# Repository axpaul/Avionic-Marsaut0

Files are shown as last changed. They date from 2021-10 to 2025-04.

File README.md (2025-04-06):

# Avionic Marsaut 0

> *© 2021 Paul Miailhe, all rights reserved.*  
> *Material licensed under [→ CC BY-NC-SA 4.0](https://creativecommons.org/licenses/by-nc-sa/4.0)*

## Experimental Rocket Avionics for Marsaut 0

The **Marsaut 0 avionics system**, designed and developed by Paul Miailhe in 2021, was successfully launched during the C'Space event. This project is licensed under **CC BY-NC-SA 4.0**.

The avionics system is based on an **STM32F303K8** microcontroller, which provides high-performance real-time control for the rocket's systems. It integrates essential sensors, motor drivers, and interface boards to ensure a robust and reliable solution for experimental rocketry.

You can access the CAD designs for all the boards [here on GrabCAD](https://grabcad.com/library/avionics-system-for-marsaut-0-rocket-mines-space-1).

---

## System Overview

The electronic architecture of the rocket is divided into the following branches:

---

- **Branch APU** (Acquisition Process Unit):  
  Responsible for acquiring, storing, and transmitting data, equipped with:  
  - **MPU6050**: A 6-axis gyroscope and accelerometer for attitude measurement.  
  - **BMP280**: A barometric pressure sensor for altitude estimation.

<p align="center">
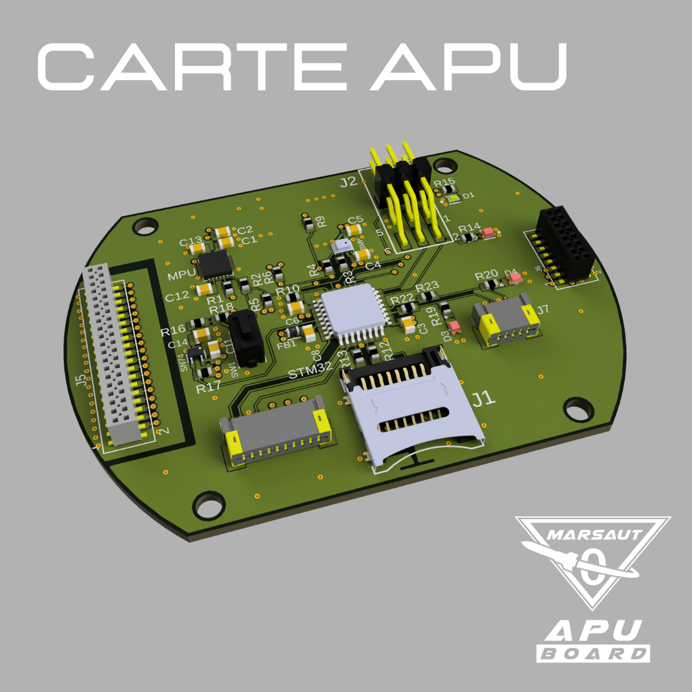
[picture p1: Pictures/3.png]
Carte APU
  
</p>

---

- **Branch SEQ** (Flight Controller):  
  The core control board, based on the **STM32F303K8**, which manages actuators and flight status monitoring.

  <p align="center">
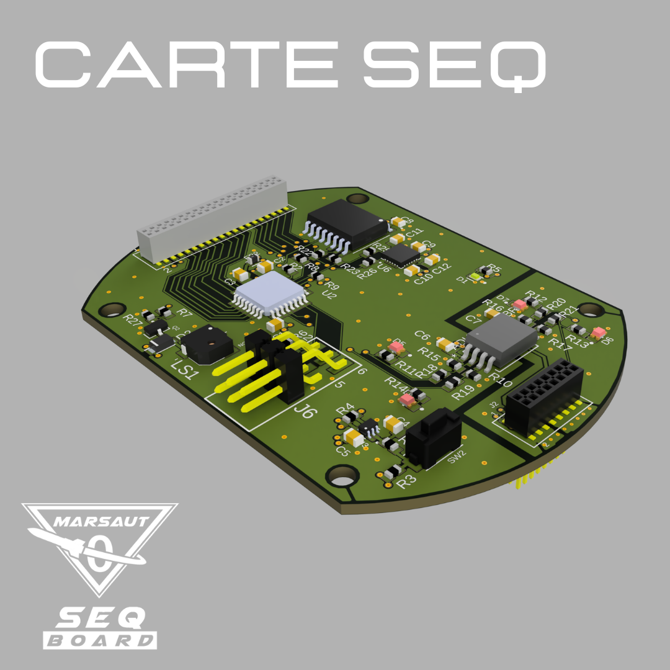
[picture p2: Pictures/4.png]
Carte SEQ
  
</p>

---

- **Branch ALIM** (Power Supply):  
  Handles power distribution and monitors the battery's state of charge.
  
  <p align="center">
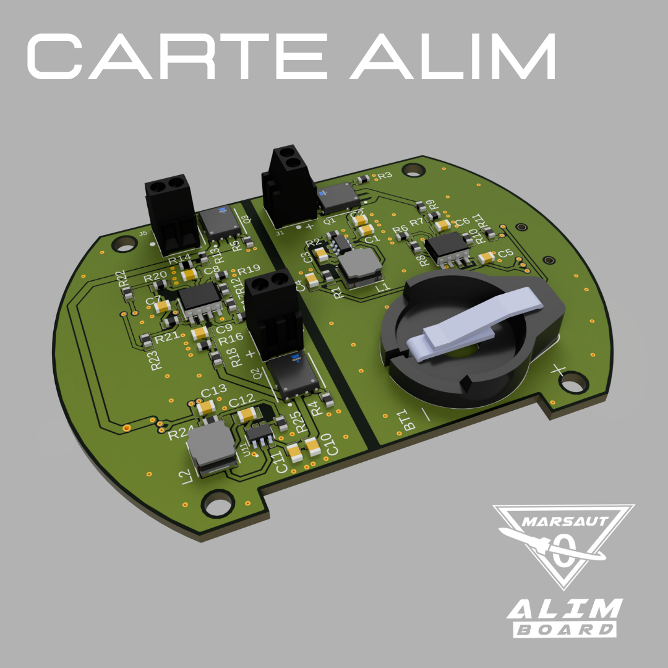
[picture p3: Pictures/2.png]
Carte ALIM
  
</p>

---

- **Branch MOTOR**:  
  Includes two **VNH5019 motor drivers** (by STMicroelectronics) for controlling the parachute deployment system.

  <p align="center">
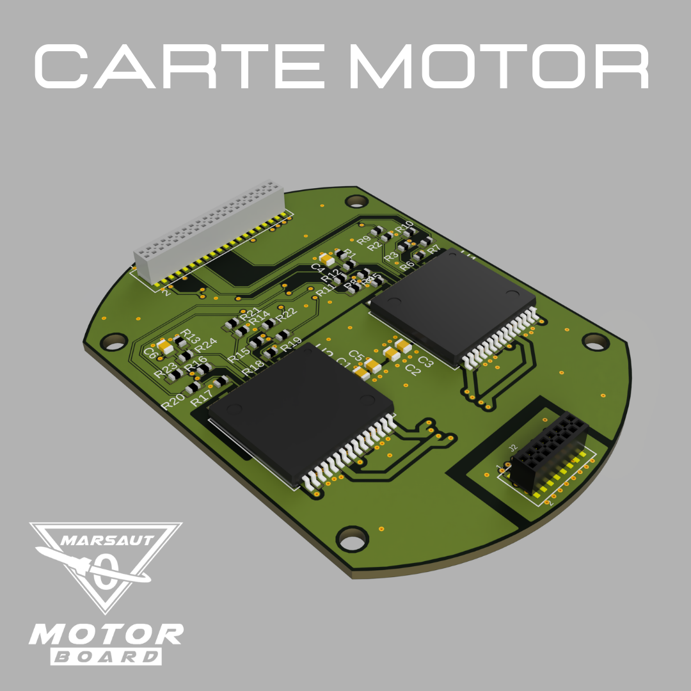
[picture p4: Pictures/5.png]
Carte MOTOR
  
</p>

---

- **Branch LINK**:  
  Connects all actuators and sensors in the rocket to the avionics for seamless operation.

    <p align="center">
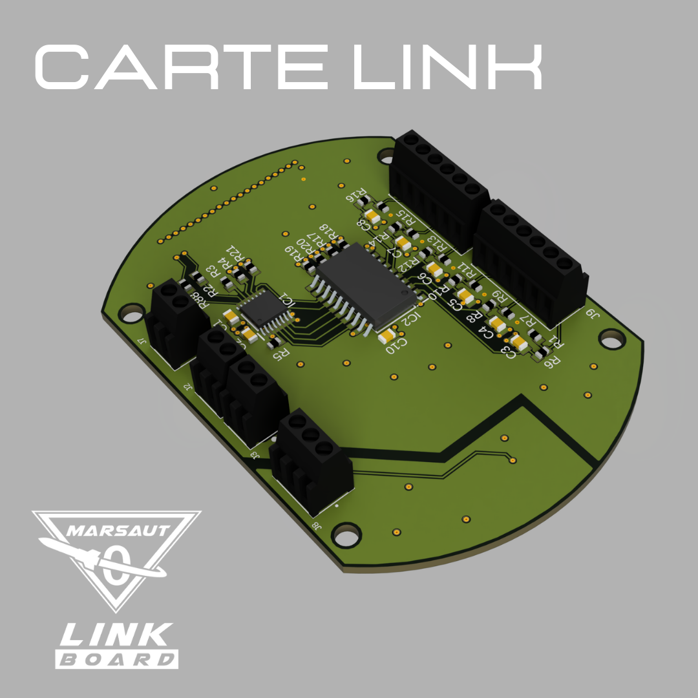
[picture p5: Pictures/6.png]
Carte LINK
  
</p>

---

- **Branch HMI** (Human-Machine Interface):  
  Provides a user interface for controlling the system and displaying key information.

---

- **Branch INT_LTS**:  
  Serves as the interface for integrating the **LoRa TTGO-T BEAM** communication module.

---

## Key Components

### **Microcontroller**
- **STM32F303K8**:  
  - ARM Cortex-M3 core with floating-point unit (FPU).  
  - Provides real-time control and data processing capabilities.

### **Sensors**
- **MPU6050**:  
  - A 6-axis IMU for measuring acceleration and angular velocity.  
  - Enables precise attitude and motion tracking.
- **BMP280**:  
  - A barometric pressure sensor for accurate altitude estimation.

### **Motor Drivers**
- **VNH5019** (by STMicroelectronics):  
  - High-power motor drivers capable of handling currents up to 12A.  
  - Used to control the parachute deployment mechanism with precision.

---

## Features and Applications

- **Real-time Control**:  
  The STM32F303K8 ensures smooth operation of actuators and sensors.  

- **Integrated Sensors**:  
  MPU6050 and BMP280 provide reliable data for navigation and altitude tracking.

- **High-Performance Motor Control**:  
  The VNH5019 motor drivers ensure precise parachute deployment and safety.

- **Seamless Communication**:  
  LoRa TTGO-T BEAM module enables efficient data transmission to ground stations.

---

## Visual Overview

### Avionics System CAD
You can find the full CAD designs of the avionics system on [GrabCAD](https://grabcad.com/library/avionics-system-for-marsaut-0-rocket-mines-space-1).

### Images
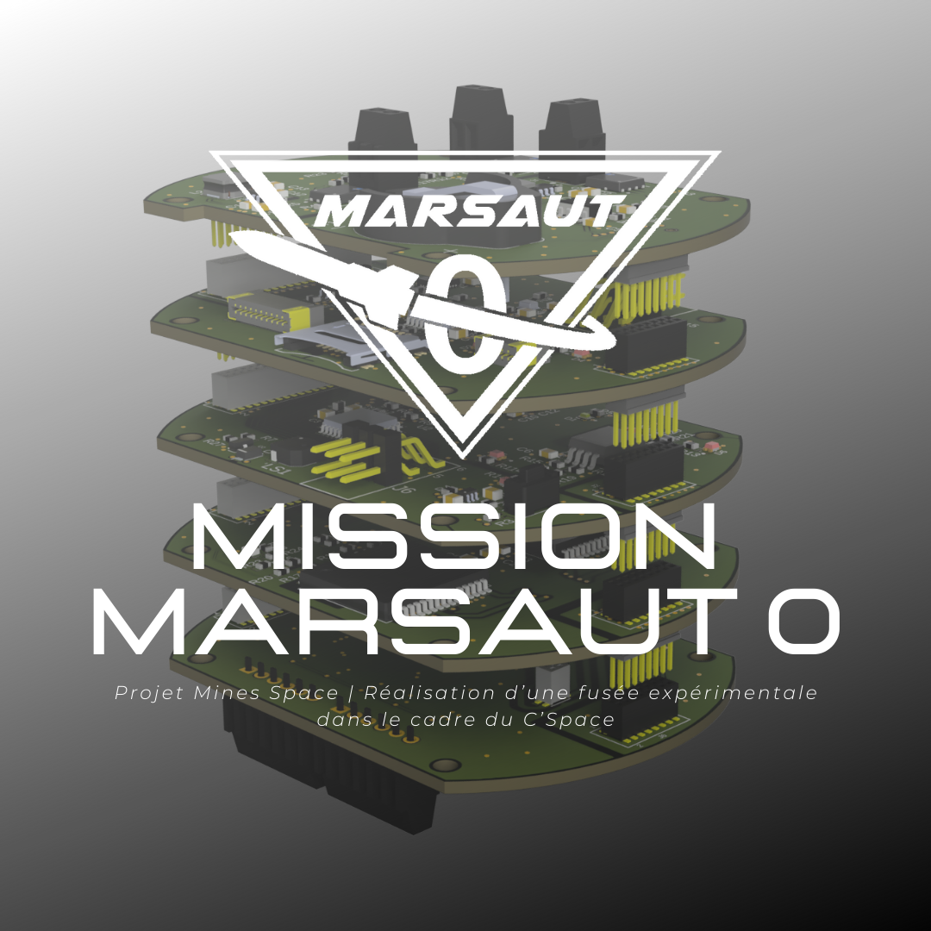
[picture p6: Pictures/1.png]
Marsaut 0 Avionics


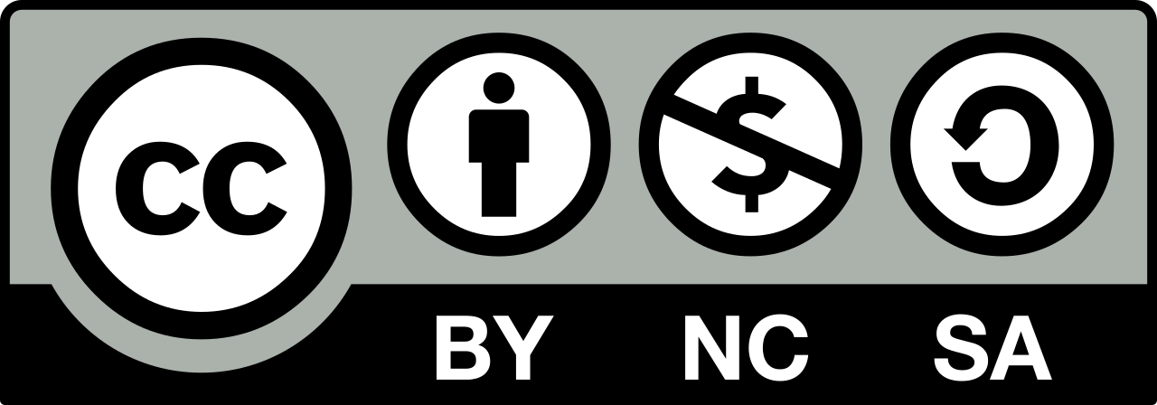
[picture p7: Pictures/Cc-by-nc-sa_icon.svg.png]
Creative Commons License


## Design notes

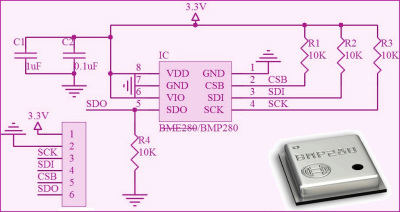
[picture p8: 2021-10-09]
LIB_MS0/Capteur/BMP280/Datasheet/3-BMP280-Module_Schematic.jpg

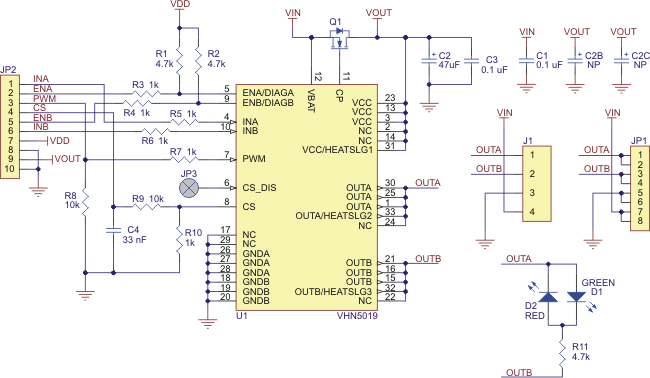
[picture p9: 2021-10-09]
LIB_MS0/DriverMotor/VNH5019ATR-E/shematic/0J3696.650.png

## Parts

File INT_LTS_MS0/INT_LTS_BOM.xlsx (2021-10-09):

Qty | Value | Device | Package | Parts | Description
2 |  | PINHD-1X13 | 1X13 | JP1, JP2 | PIN HEADER
2 | 0R | R-EU_R0603 | R0603 | R1, R2 | RESISTOR, European symbol
2 | 110R | R-EU_R0603 | R0603 | R3, R15 | RESISTOR, European symbol
1 | BROADCOM_HSMA-C190BROADCOM_HSMA-C190_0_0 | BROADCOM_HSMA-C190BROADCOM_HSMA-C190_0_0 | BROADCOM_HSMA-C190_0 | LED_APU_AMBER | Amber 592nm LED Indication - Discrete 1.9V 0603 (1608 Metric)
1 | BROADCOM_HSMH-C170BROADCOM_HSMH-C170_0_0 | BROADCOM_HSMH-C170BROADCOM_HSMH-C170_0_0 | BROADCOM_HSMH-C170_0 | LED_APU_RED | LED RED DIFFUSED 0805 SMD
1 | FC1-05-02-T-WT-TR | FC1-05-02-T-WT-TR | FC10502TWTTR | J7 | FFC & FPC Connectors 1.00 mm Flat Flexible Cable (FFC) Socket Strip

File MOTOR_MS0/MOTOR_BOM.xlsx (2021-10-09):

Qty | Value | MPN | Package | Parts | Description | LCSC Part
10 | 0R | 0603WAF0000T5E | R0603 | R7, R8, R9, R10, R11, R19, R20, R21, R22, R23 | RESISTOR, European symbol | C21189
6 | 100K | 0603WAF1003T5E | R0603 | R2, R5, R6, R14, R17, R18 | RESISTOR, European symbol | C25803
2 | 10k | 0603WAF1002T5E | R0603 | R12, R24 | RESISTOR, European symbol | C25804
2 | 33nF | 0805B333K500NT | C0805 | C4, C6 | CAPACITOR, European symbol | C1739
4 | 3K3 | 0603WAF3301T5E | R0603 | R3, R4, R15, R16 | RESISTOR, European symbol | C22978
4 | 22uF | CL21A226MAQNNNE | C0805 | C1, C2, C3, C5 | CAPACITOR, European symbol | C45783
2 | 5K6 | 0603WAF5601T5E | R0603 | R1, R13 | RESISTOR, European symbol | C23189
1 | FLE-108-01-XX-DV | NON-CONNECTED | FLE-108-01-XX-DV | J2 | DOUBLE ROW 0.050X0.050" STRIP ASSEMBLY. Check prices"
1 | FLE-120-01-XX-DV | NON-CONNECTED | FLE-120-01-XX-DV | J5 | DOUBLE ROW 0.050X0.050" STRIP ASSEMBLY. Check prices"
1 | FTSH-102-05-F-DV | NON-CONNECTED | FTSH-102-XX-YYY-DV | J1 | 4 Position, High Reliability Header Strips, 0.050 pitch"
1 | FTSH-108-05-F-DV-A | NON-CONNECTED | FTSH-108-XX-YYY-DV-A | J4 | 16 Position, High Reliability Header Strips, 0.050 pitch"
1 | FTSH-120-05-F-DV | NON-CONNECTED | FTSH-120-XX-YYY-DV | J3 | 40 Position, High Reliability Header Strips, 0.050 pitch"
2 | VNH5019ATR-E | NON-CONNECTED | IC_VNH5019ATR-E | U1, U2 | Motor / Motion / Ignition Controllers & Drivers Automotive h-Bridge 18mohm 30a 41v Vcc Check prices

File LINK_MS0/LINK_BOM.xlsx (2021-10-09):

Qty | Value | MPN | Package | Parts | Description | LCSC Part
8 | 0R | 0603WAF0000T5E | R0603 | R2, R4, R17, R18, R19, R20, R21, R88 | RESISTOR, European symbol | C21189
9 | 100nF | CC0805KRX7R9BB104 | C0805 | C1, C2, C3, C4, C5, C6, C7, C8, C10 | CAPACITOR, European symbol | C49678
13 | 10K | 0603WAF1002T5E | R0603 | R1, R3, R6, R7, R8, R9, R10, R11, R12, R13, R14, R15, R16 | RESISTOR, European symbol | C25804
3 | 282834-2 | NON-CONNECTED | CONN_282834-2 | J2, J3, J7 | Terminal block; 2.54mm; angled 90Â°; 0.03Ã·1mm2; ways: 2; 10A; H: 10mm Check prices
1 | 282834-3 | NON-CONNECTED | TE_282834-3 | J8 | Conn; Term Blk; PCB; Wire Receptacle; 3; 2.54mm; 30-16AWG; Green; 10A; 150V; M1.6 Check prices
2 | 282834-6 | NON-CONNECTED | TE_282834-6 | J4, J9 | TERM BLOCK 6POS SIDE ENT 2.54MM Check prices
1 | 4K7 | 0603WAF4701T5E | R0603 | R5 | RESISTOR, European symbol | C23162
1 | 74HC7541D,118 | NON-CONNECTED | SOIC127P1032X265-20N | IC2 | 74HC(T)7541 - Octal Schmitt trigger buffer/line driver; 3-state@en-us
1 | FLE-102-01-G-DV | NON-CONNECTED | SAMTEC_FLE-102-01-G-DV | J1 | Check prices
1 | FLE-108-01-XX-DV | NON-CONNECTED | FLE-108-01-XX-DV | J6 | DOUBLE ROW 0.050X0.050" STRIP ASSEMBLY. Check prices"
1 | FLE-120-01-XX-DV | NON-CONNECTED | FLE-120-01-XX-DV | J5 | DOUBLE ROW 0.050X0.050" STRIP ASSEMBLY. Check prices"
1 | TCA6408AQPWRQ1 | NON-CONNECTED | SOP65P640X120-16N | IC1 | Automotive Low-Voltage 8-Bit I2C and SMBus I/O Expander With Interrupt Output

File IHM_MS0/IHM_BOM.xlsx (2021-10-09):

Qty | Value | MPN | Package | Parts | Description | LCSC Part
1 |  | NON-CONNECTED | 1X04 | JP1 | PIN HEADER
3 | 0R | 0603WAF0000T5E | R0603 | R2, R4, R21 | RESISTOR, European symbol | C21189
5 | 100nF | CC0805KRX7R9BB104 | C0805K | C1, C2, C4, C6, C8 | CAPACITOR, European symbol | C49678
4 | 10K | 0603WAF1002T5E | R0603 | R3, R6, R7, R20 | RESISTOR, European symbol | C25804
7 | 110R | NON-CONNECTED | R0603 | R1, R13, R14, R15, R16, R17, R18 | RESISTOR, European symbol
3 | 147873-1 | NON-CONNECTED | SW_147873-1 | SW1, SW2, SW3 | Switch Tactile OFF (ON) SPST Rectangular Button J-Bend 0.05A 24VDC 1.77N SMD T/R Check prices
3 | 1K | 0603WAF1001T5E | R0603 | R10, R11, R12 | RESISTOR, European symbol | C21190
3 | 2u2F | 0805F225M500NT | C0805K | C3, C5, C7 | CAPACITOR, European symbol | C49217
1 | 4K7 | 0603WAF4701T5E | R0603 | R5 | RESISTOR, European symbol | C23162
3 | BROADCOM_ASMT-RF45-AN002BROADCOM_ASMT-RF45-AN002_0_0 | NON-CONNECTED | BROADCOM_ASMT-RF45-AN002_0 | LAG, LMG, LSG | LED YLW/GREEN DIFFUSED 0603 SMD
1 | BROADCOM_HSMA-C190BROADCOM_HSMA-C190_0_0 | NON-CONNECTED | BROADCOM_HSMA-C190_0 | LIP | Amber 592nm LED Indication - Discrete 1.9V 0603 (1608 Metric)
3 | BROADCOM_HSMH-C170BROADCOM_HSMH-C170_0_0 | NON-CONNECTED | BROADCOM_HSMH-C170_0 | LAR, LMR, LSD | LED RED DIFFUSED 0805 SMD
1 | FC1-10-02-T-WT-TR | NON-CONNECTED | FC11002TWTTR | J1 | FFC & FPC Connectors 1.00 mm Flat Flexible Cable (FFC) Socket Strip
3 | SN74LVC1G17DCKR | NON-CONNECTED | SOT65P210X110-5N | U1, U2, U3 | Check prices
1 | TCA6408AQPWRQ1 | NON-CONNECTED | SOP65P640X120-16N | IC1 | Automotive Low-Voltage 8-Bit I2C and SMBus I/O Expander With Interrupt Output

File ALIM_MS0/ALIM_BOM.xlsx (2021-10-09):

Qty | Value | MPN | Package | Parts | Description | LCSC Part Number(optional)
3 | 0R | 0603WAF0000T5E | R0603 | R11, R22, R23 | RESISTOR, European symbol | C21189
3 | 100R | NON-CONNECTED | R0603 | R3, R4, R5 | RESISTOR, European symbol
6 | 100nF | CC0805KRX7R9BB104 | C0805 | C1, C3, C5, C7, C10, C12 | CAPACITOR, European symbol | C49678
8 | 10K | 0603WAF1002T5E | R0603 | R2, R6, R10, R15, R19, R20, R21, R25 | RESISTOR, European symbol | C25804
5 | 10uF | CL21A106KAYNNNE | C0805 | C2, C6, C8, C9, C11 | CAPACITOR, European symbol | C15850
3 | 12K | 0603WAF1202T5E | R0603 | R8, R12, R17 | RESISTOR, European symbol | C22790
3 | 13K | 0603WAF1302T5E | R0603 | R9, R13, R18 | RESISTOR, European symbol | C22797
2 | 22uF | CL21A226MAQNNNE | C0805 | C4, C13 | CAPACITOR, European symbol | C45783
3 | 282834-2 | NON-CONNECTED | TROUGH HOLE | J1, J2, J5 | Terminal block; 2.54mm; angled 90Â°; 0.03Ã·1mm2; ways: 2; 10A; H: 10mm Check prices
2 | 33K | 0603WAF3302T5E | R0603 | R1, R24 | RESISTOR, European symbol | C4216
3 | 3K | 0603WAF3001T5E | R0603 | R7, R14, R16 | RESISTOR, European symbol | C4211
1 | BH600 | NON-CONNECTED | BAT_BH600 | BT1 | BATTERY HOLDER COIN 16MM PC PIN Check prices
1 | FTSH-108-05-F-DV-A | NON-CONNECTED | CONNECTOR_SMT | J4 | 16 Position, High Reliability Header Strips, 0.050 pitch"
1 | FTSH-120-05-F-DV | NON-CONNECTED | CONNECTOR_SMT | J3 | 40 Position, High Reliability Header Strips, 0.050 pitch"
2 | LQH5BPB2R2NT0L | NON-CONNECTED | SMT | L1, L2 | Inductor Power Chip Shielded Wirewound 1.2uH 30% 100KHz Ferrite 3.1A 0.0228Ohm DCR 2020 T/R Check prices
2 | TLV9022DR | NON-CONNECTED | SOIC-8 | TLV1, TLV2
2 | TPS565201DDCR | NON-CONNECTED | SOT95P280X110-6N | U10, U11 | Check prices
3 | SI7463DP-T1-E3 | NON-CONNECTED | VISHAY_SI7463DP-T1-E3_0 | Q1, Q2, Q3 | MOSFET 40V 18.6A 5.4W 9.2mohm @ 10V

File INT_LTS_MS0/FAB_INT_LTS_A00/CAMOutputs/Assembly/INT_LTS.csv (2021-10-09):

Qty | Value | Device | Package | Parts | Description | ARROW_PART_NUMBER | ARROW_PRICE-STOCK | AUTOMOTIVE | CENTROID_NOT_SPECIFIED | COLOUR | DATASHEET | DESCRIPTION | DEVICE_CLASS_L1 | DEVICE_CLASS_L2 | DEVICE_CLASS_L3 | DIGIKEY_DESCRIPTION | DIGIKEY_PART_NUMBER | FOOTPRINT_VARIANT_NAME_0 | FORWARD_CURRENT | FORWARD_VOLTAGE | HEIGHT | LEAD_FREE | LED_ORIENTATION | LUMINOUS_INTENSITY | MANUFACTURER_NAME | MANUFACTURER_PART_NUMBER | MAX_JUNCTION_TEMP | MF | MFG_PACKAGE_IDENT | MFG_PACKAGE_IDENT_DATE | MFG_PACKAGE_IDENT_REV | MOUSER_DESCRIPTION | MOUSER_PART_NUMBER | MOUSER_PRICE-STOCK | MPN | PACKAGE | PEAK_EMMISION_WAVELENGTH | POPULARITY | POWER_DISSIPATION | PREFIX | REVERSE_VOLTAGE | ROHS | SPICEPREFIX | STANDOFF_HEIGHT | TEMPERATURE_RANGE_HIGH | TEMPERATURE_RANGE_LOW | VERIFICATION_VERSION | VIEWING_ANGLE | VOLTAGE | WAVELENGTH
2 |  | PINHD-1X13 | 1X13 | JP1, JP2 | PIN HEADER |  |  |  |  |  |  |  |  |  |  |  |  |  |  |  |  |  |  |  |  |  |  |  |  |  |  |  |  |  |  |  |  | 5
2 | 0R | R-EU_R0603 | R0603 | R1, R2 | RESISTOR, European symbol |  |  |  |  |  |  |  |  |  |  |  |  |  |  |  |  |  |  |  |  |  |  |  |  |  |  |  |  |  |  |  |  | 70 |  |  |  |  | R
2 | 110R | R-EU_R0603 | R0603 | R3, R15 | RESISTOR, European symbol |  |  |  |  |  |  |  |  |  |  |  |  |  |  |  |  |  |  |  |  |  |  |  |  |  |  |  |  |  |  |  |  | 70 |  |  |  |  | R
1 | BROADCOM_HSMA-C190BROADCOM_HSMA-C190_0_0 | BROADCOM_HSMA-C190BROADCOM_HSMA-C190_0_0 | BROADCOM_HSMA-C190_0 | LED_APU_AMBER | Amber 592nm LED Indication - Discrete 1.9V 0603 (1608 Metric) |  |  | No | No | Amber | https://docs.broadcom.com/doc/AV02-0112EN |  | Optoelectronics | LEDs | unset | LED AMBER DIFFUSED CHIP SMD | 516-1423-1-ND | Recommended_Land_Pattern | 20mA | 1.9V | 0.9mm | Yes | Top View | 90mcd |  |  | +95°C | Broadcom | 0 | 0 | 0 | LED Uni-Color Amber 595nm 2-Pin Chip LED T/R | 630-HSMA-C190 |  | HSMA-C190 | 0603 | 595nm |  | 60mW | D | 5V | Yes |  |  | +85°C | -40°C | 0.0.0.3 | 170° | 1.9V | 592nm
1 | BROADCOM_HSMH-C170BROADCOM_HSMH-C170_0_0 | BROADCOM_HSMH-C170BROADCOM_HSMH-C170_0_0 | BROADCOM_HSMH-C170_0 | LED_APU_RED | LED RED DIFFUSED 0805 SMD |  |  |  | No | Red | https://media.digikey.com/pdf/Data%20Sheets/Avago%20PDFs/HSMz-Czzz.pdf |  | Optoelectronics | LEDs | unset | DIODE LED RED DIFFUSED 0805 SMD | 516-1427-1-ND |  | 25mA | 1.8V | 0.9mm | yes | Top View | 17mcd |  |  | +95°C | Broadcom | HSMH-C170 | 0 | 0 |  | 630-HSMH-C170 |  | HSMH-C170 | 0805 (2012 metric) |  |  | 65mW | D | 5V | yes |  | 0mm | +85°C | -40°C | 0.0.0.1 | 170° |  | 639nm
1 | FC1-05-02-T-WT-TR | FC1-05-02-T-WT-TR | FC10502TWTTR | J7 | FFC & FPC Connectors 1.00 mm Flat Flexible Cable (FFC) Socket Strip |  |  |  |  |  |  | FFC & FPC Connectors 1.00 mm Flat Flexible Cable (FFC) Socket Strip |  |  |  |  |  |  |  |  | 5.19mm |  |  |  | SAMTEC | FC1-05-02-T-WT-TR |  |  |  |  |  |  | 200-FC10502TWTTR | https://www.mouser.co.uk/ProductDetail/Samtec/FC1-05-02-T-WT-TR?qs=rU5fayqh%252BE0IHNLE7hd%252B7w%3D%3D

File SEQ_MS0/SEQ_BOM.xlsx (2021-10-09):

Qty | Value | MPN | Package | Parts
10 | 0R | CRCW06030000Z0EAC | R0603 | R1,R18, R19, R20, R21, R22, R23, R25, R26, R24
4 | 100K | ERJ-UP3D1003V | R0603 | R10, R15, R16, R17
6 | 100nF | C0805X104M5RACTU | C0805 | C6, C7, C8, C9, C10, C12
2 | 10K | ERJ-UP3F1002V | R0603 | R2, R27
6 | 110R | ERJ-UP3F1100V | R0603 | R5, R6, R11, R12, R13, R14
1 | 147873-1 |  | SW_147873-1 | SW2
1 | 330R | ERJ-UP3D1001V | R0603 | R7
1 | 1uF | C0805X105K3RAC3316 | C0805K | C3
1 | 2.2nF | C0805C222K3GECTU | C0805 | C11
1 | 2u2F | C0805C225K3RACTU | C0805K | C4
2 | 4K7 | ERJ-UP3D4701V | R0603 | R8, R9
2 | 4u7F | C0805C475K3RACTU | C0805K | C1, C2
1 | ADUM226N1BRIZ | ADUM226N1BRIZ | RI_8_1_ADI | U4
1 | BROADCOM_ASMT-RF45-AN002BROADCOM_ASMT-RF45-AN002_0_0 | ASMT-RF45-AN002 | BROADCOM_ASMT-RF45-AN002_0 | D1
1 | BROADCOM_HSMA-C190BROADCOM_HSMA-C190_0_0 | HSMA-C190 | BROADCOM_HSMA-C190_0 | D3
4 | BROADCOM_HSMH-C170BROADCOM_HSMH-C170_0_0 | HSMH-C170 | BROADCOM_HSMH-C170_0 | D4, D5, D6, D7
1 | CSS-0575A-SMT | CSS-0575A-SMT-TR | CUI_CSS-0575A-SMT | LS1
1 | DS3231S | DS3231S# | SOIC127P1032X265-16N | U5
1 | FLE-108-01-XX-DV | FLE-108-01-G-DV | FLE-108-01-XX-DV | J2
1 | FLE-120-01-XX-DV | FLE-120-01-G-DV | FLE-120-01-XX-DV | J5
1 | FTSH-108-05-F-DV-A | FTSH-108-05-F-DV-A | FTSH-108-XX-YYY-DV-A | J1
1 | FTSH-120-05-F-DV | FTSH-120-05-F-DV | FTSH-120-XX-YYY-DV | J3
1 | MPU-6050 | MPU-6050 | QFN50P400X400X95-24N | U6
1 | NRVTS260ESFT1G | RBR2MM40CTFTR | SODFL3616X98N | D2
1 | NTR4501NT1G | NTR4501NT1G | SOT95P237X111-3N | Q2
1 | SAMTEC-TSM-103-01-X-DHJ | TSM-103-01-F-DV-P-TR | SAMTEC-TSM-103-01-X-DH | J6
1 | SN74LVC1G17DCKR | SN74LVC1G17DCKR | SOT65P210X110-5N | U3
1 | STM32F303K8T6 | STM32F303K8T6 | QFP80P900X900X160-32N | U2
1 | TDK_MMZ1608S601ATA00TDK_MMZ1608S601ATA00_0_0 | MMZ1608S601ATA00 | TDK_MMZ1608S601ATA00_0 | FB2

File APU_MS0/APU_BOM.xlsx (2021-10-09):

Qty | Value | MPN | Package | Parts
13 | 0R | CRCW06030000Z0EAC | R0603 | R1, R2, R3, R4, R7, R8, R9, R11, R12, R13, R16, R22, R23
8 | 100nF | C0805X104M5RACTU | C0805 | C1, C2, C4, C5, C7, C9, C10, C13
1 | 10K | ERJ-UP3F1002V | R0603 | R10
4 | 110R | ERJ-UP3F1100V | R0603 | R14, R15, R19, R20
1 | 147873-1 |  | SMT | SW1
1 | 1uF | C0805X105K3RAC3316 | C0805K | C8
1 | 2.2nF | C0805C222K3GECTU | C0805 | C12
1 | 0.1uF | C0805C225K3RACTU | C0805 | C14
3 | 4K7 | ERJ-UP3D4701V | R0603 | R5, R6, R21
2 | 4u7F | C0805C475K3RACTU | C0805 | C3, C6
1 | BMP280 | AliExpress | SMT | BMP
1 | BROADCOM_ASMT-RF45-AN002BROADCOM_ASMT-RF45-AN002_0_0 | ASMT-RF45-AN002 | SMT | D1
1 | BROADCOM_HSMA-C190BROADCOM_HSMA-C190_0_0 | HSMA-C190 | SMT | D2
2 | BROADCOM_HSMH-C170BROADCOM_HSMH-C170_0_0 | HSMH-C170 | SMT | D3, D4
1 | DS3231S | DS3231S# | SOIC127P1032X265-16N | DS
1 | FC1-05-02-T-WT-TR | FC1-05-02-T-WT-TR | SMT | J7
1 | FC1-10-02-T-WT-TR | FC1-10-02-T-WT | SMT | J8
1 | FLE-108-01-XX-DV | FLE-108-01-G-DV | SMT | J6
1 | FLE-120-01-XX-DV | FLE-120-01-G-DV | SMT | J5
1 | FTSH-108-05-F-DV-A | FTSH-108-05-F-DV-A | SMT | J4
1 | FTSH-120-05-F-DV | FTSH-120-05-F-DV | SMT | J3
1 | MEM2067-02-180-00-A_REVB |  | SMT | J1
1 | MPU-6050 | MPU-6050 | QFN50P400X400X95-24N | MPU
1 | SAMTEC-TSM-103-01-X-DHJ | TSM-103-01-F-DV-P-TR | SMT | J2
1 | SN74LVC1G17DCKR | SN74LVC1G17DCKR | SOT65P210X110-5N | SN74
1 | STM32F303K8T6 | STM32F303K8T6 | QFP80P900X900X160-32N | STM32
1 | TDK_MMZ1608S601ATA00TDK_MMZ1608S601ATA00_0_0 | MMZ1608S601ATA00 | SMT | FB1

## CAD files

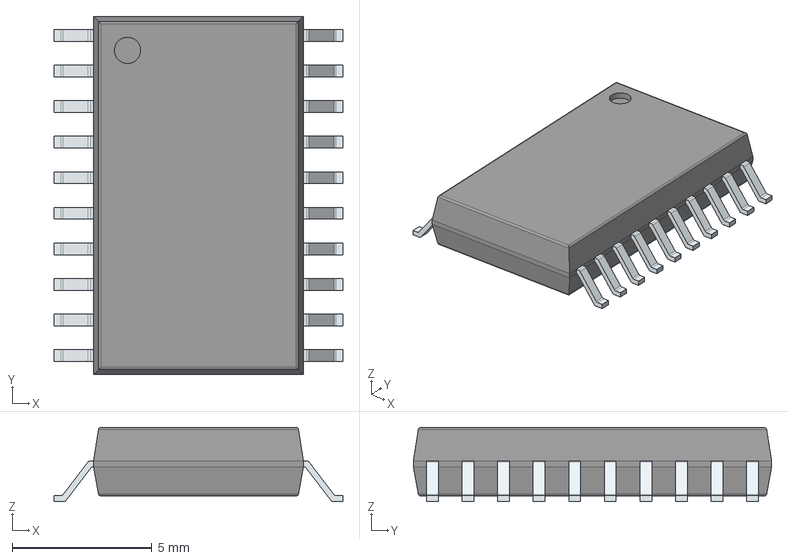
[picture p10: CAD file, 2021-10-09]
LIB_MS0/Analogique/74HC7541/74HC7541D,118.stp
10.3 x 12.8 x 2.65 mm
PinsArrayLR

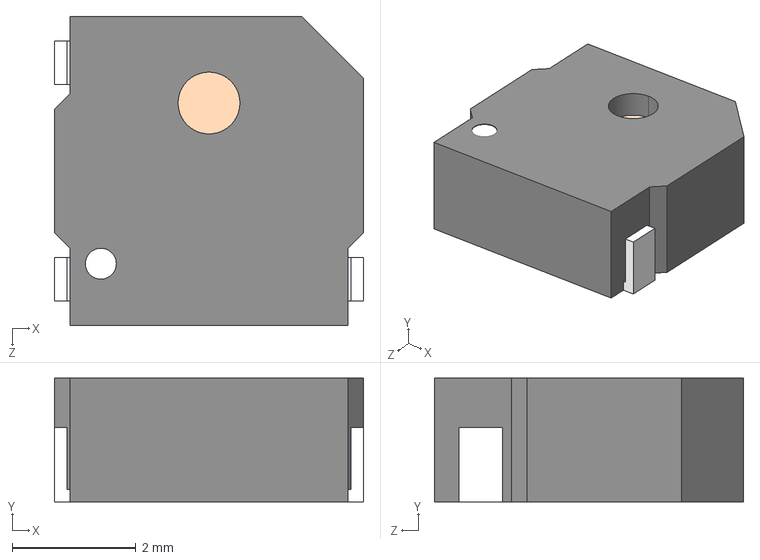
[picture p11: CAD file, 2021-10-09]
LIB_MS0/Analogique/CSS-0575A-SMT-TR/CUI_DEVICES_CSS-0575A-SMT-TR.step
5.00 x 2.00 x 5.00 mm

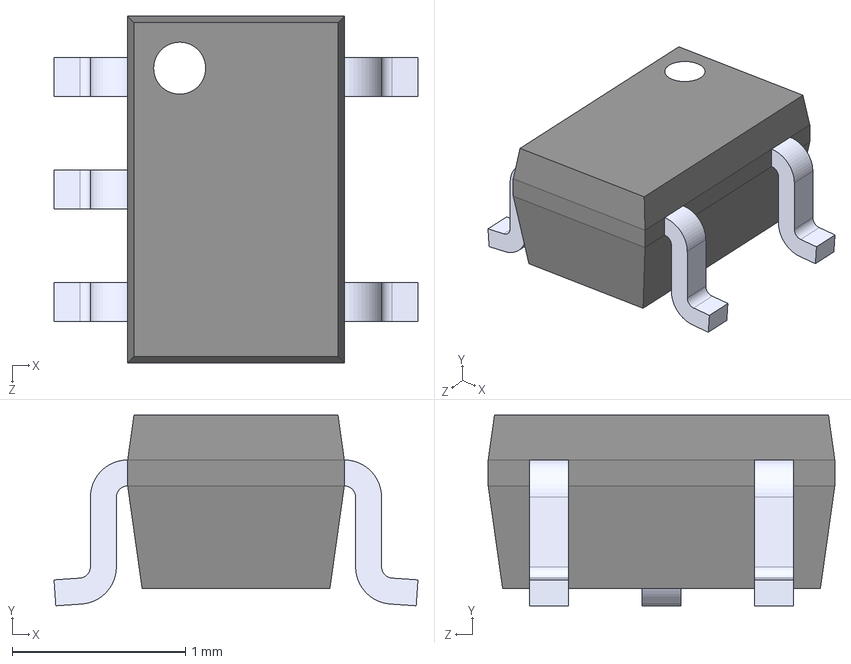
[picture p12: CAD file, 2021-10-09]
LIB_MS0/Analogique/SN74LVC1G17DCKR/SN74LVC1G17DCKR.STEP
2.10 x 1.10 x 2.00 mm

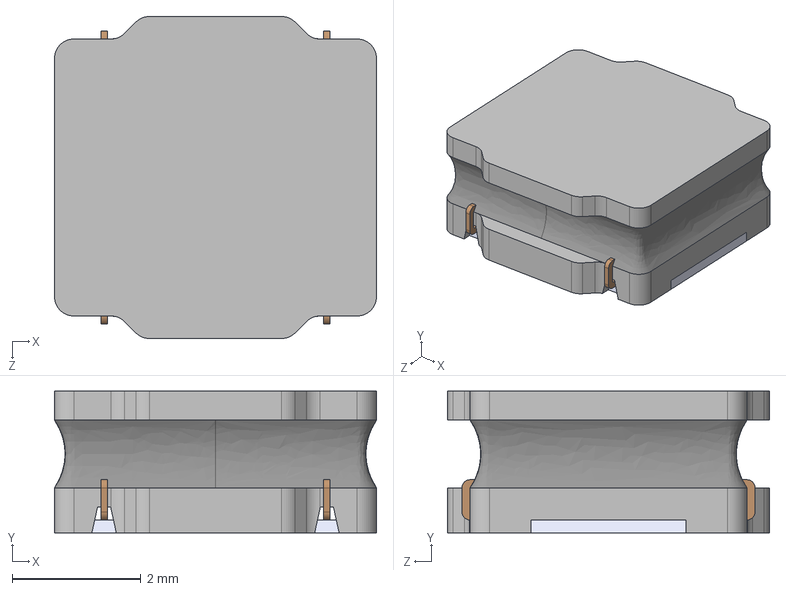
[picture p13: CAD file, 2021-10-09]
LIB_MS0/Bobine/LQH5BPB2R2NT0L/LQH5BPB2R2NT0L.STEP
5.00 x 2.20 x 5.00 mm

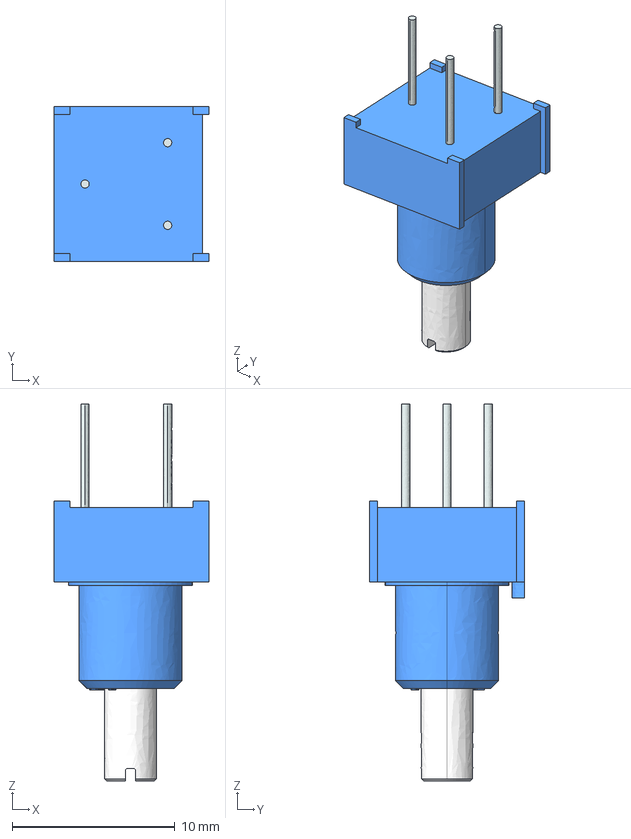
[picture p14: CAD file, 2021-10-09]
LIB_MS0/Bouton_Potar/3310Y-001-103L/3310y-001-103l.stp
9.52 x 9.53 x 23.2 mm

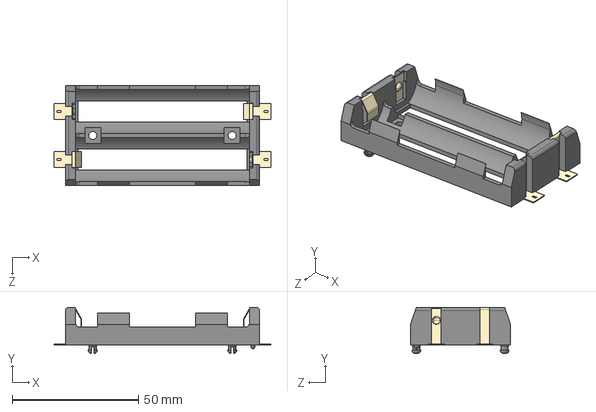
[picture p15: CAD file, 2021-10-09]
LIB_MS0/Box_Holder/1048P-Battery Holder (Open) 18650 2 Cell/1048P--3DModel-STEP-56544.STEP
86.0 x 18.3 x 39.8 mm

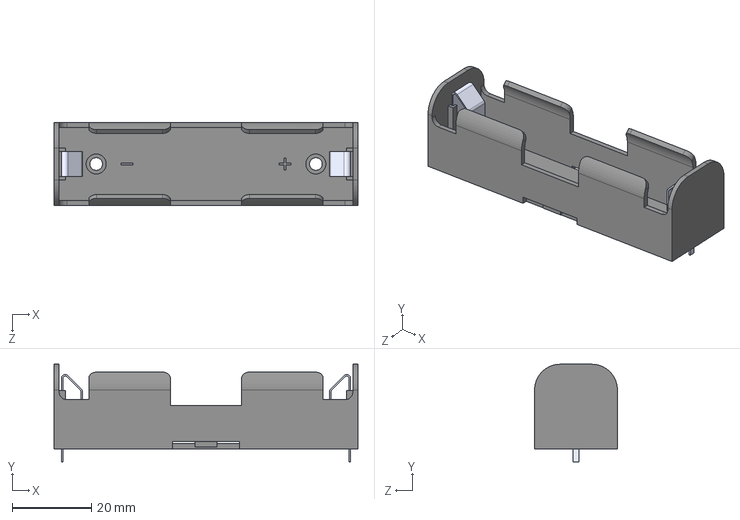
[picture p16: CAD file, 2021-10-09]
LIB_MS0/Box_Holder/BH-18650-PC/BK-18650-PC2--3DModel-STEP-56544.STEP
77.0 x 24.7 x 21.0 mm

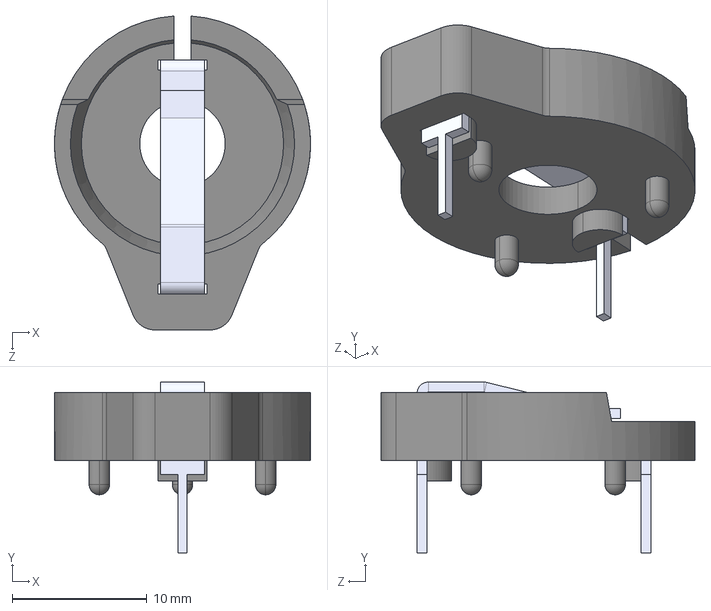
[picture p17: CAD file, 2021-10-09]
LIB_MS0/Box_Holder/BH600/BH600--3DModel-STEP-1.STEP
19.0 x 12.7 x 23.3 mm

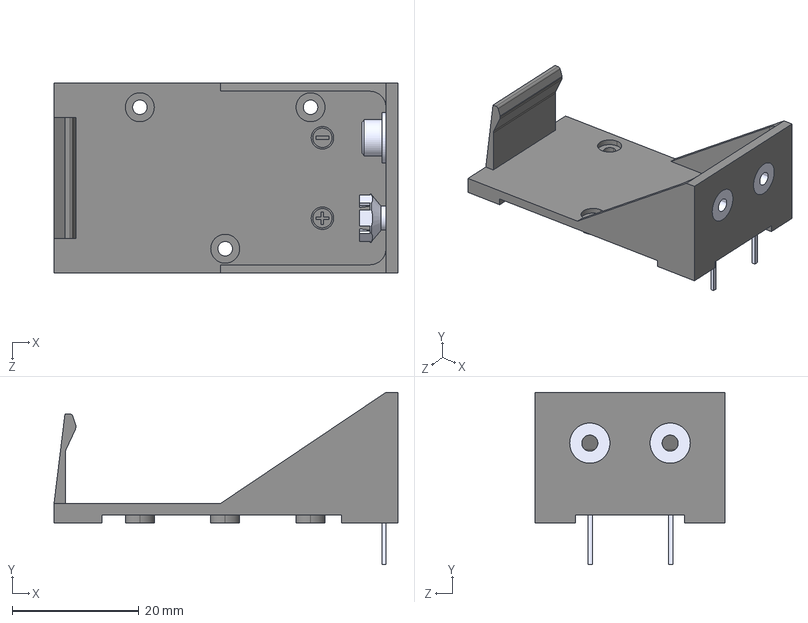
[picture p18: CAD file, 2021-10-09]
LIB_MS0/Box_Holder/BH9VPC/BH9VPC--3DModel-STEP-56544.STEP
54.4 x 27.2 x 30.0 mm

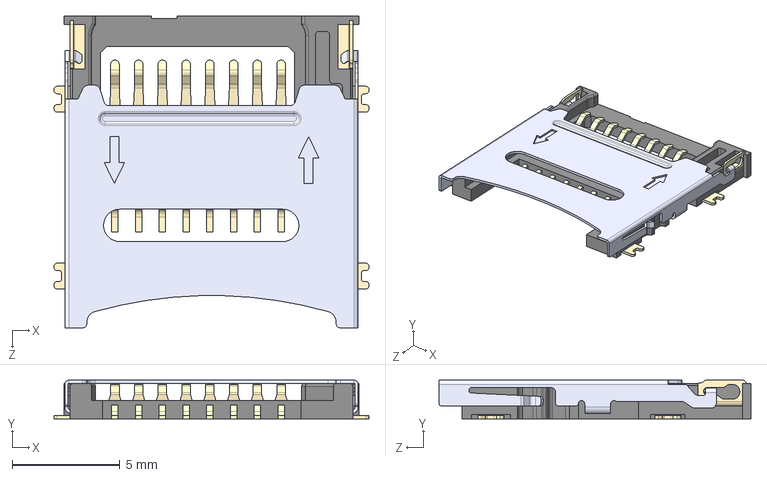
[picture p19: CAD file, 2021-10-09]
LIB_MS0/Box_Holder/Card_Connector_MEM2067-02-180-00-A/MEM2067-02-180-00-A--3DModel-STEP-56544.STEP
14.6 x 1.80 x 14.5 mm

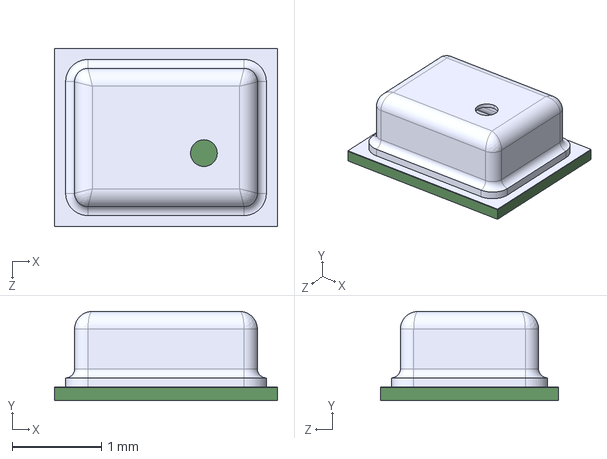
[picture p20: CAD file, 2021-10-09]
LIB_MS0/Capteur/BMP280/BMP280--3DModel-STEP-1.STEP
2.50 x 1.00 x 2.00 mm

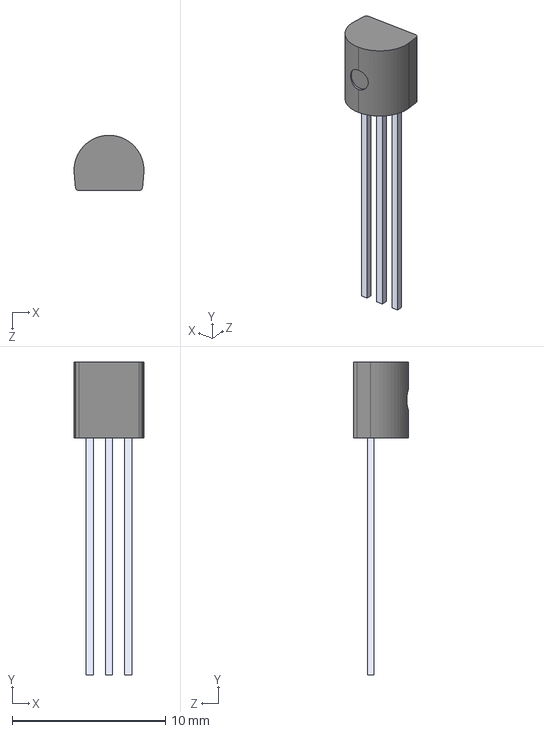
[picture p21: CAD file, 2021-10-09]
LIB_MS0/Capteur/DS18B20/DS18B20+.STEP
4.57 x 20.4 x 3.62 mm

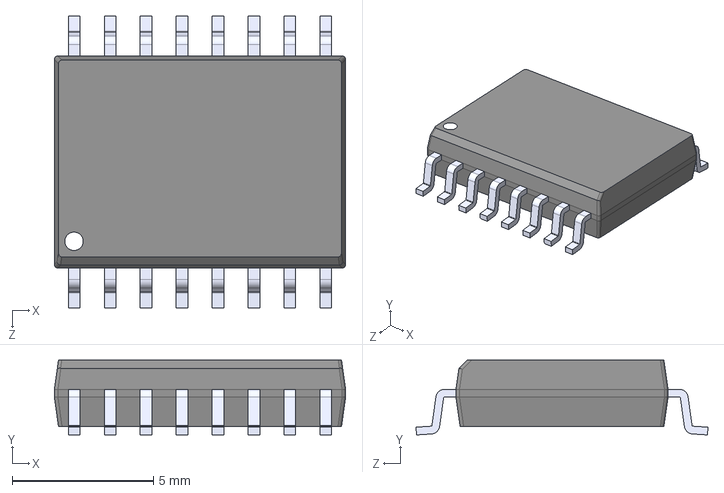
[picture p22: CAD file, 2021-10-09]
LIB_MS0/Capteur/DS3231S/DS3231S.STEP
10.3 x 2.65 x 10.3 mm

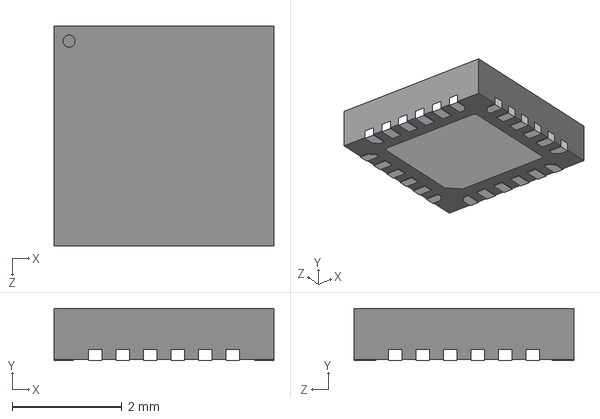
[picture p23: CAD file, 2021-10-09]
LIB_MS0/Capteur/MPU6050/MPU-6050--3DModel-STEP-1.STEP
4.00 x 0.95 x 4.00 mm

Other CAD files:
LIB_MS0/diode/NRVTS260ESFT1G/NRVTS260ESFT1G.stp
LIB_MS0/DriverMotor/VNH5019ATR-E/VNH5019ATR-E--3DModel-STEP-56544.STEP
LIB_MS0/Ferrite/TDK MMZ1608S601ATA00/MMZ1608S601ATA00.step
LIB_MS0/Isolateur/ADUM226N1BRIZ/RI_8_1_ADI.step
LIB_MS0/Bouton_Potar/147873-1/147873-1.stp
LIB_MS0/Isolateur/ISO1541D/ISO1541D.STEP
LIB_MS0/Isolateur/VOM617A-6X001T/VOM617A-6X001T.STEP
LIB_MS0/Led/ASMT-RF45-AN002/06695f22abd46c4b359e0e4e7049cb9a821bc6c2.step
LIB_MS0/Led/HSMA-C190/2ae01f472773d4857e096d23aa399efa93f8c2e4.step
LIB_MS0/Led/HSMH-C170/2ae01f472773d4857e096d23aa399efa93f8c2e4.step
LIB_MS0/Mosfet/IRFHS8342TRPBF/IRFHS8342TRPBF.step
LIB_MS0/Mosfet/NTR4501NT1G/NTR4501NT1G.STEP
LIB_MS0/Mosfet/SI1308EDL-T1-GE3/5b5cd14e6a0eab1b8b6f0e12559ce02876c953cb.step
LIB_MS0/Mosfet/SI7463DP-T1-E3/ae5fa6859b2fad152b1f9b916d57e8ae57631f3c.step
LIB_MS0/Mutiplexeur/PCF8574ADW/PCF8574ADW.STEP
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

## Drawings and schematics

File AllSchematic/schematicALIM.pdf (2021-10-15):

A

A

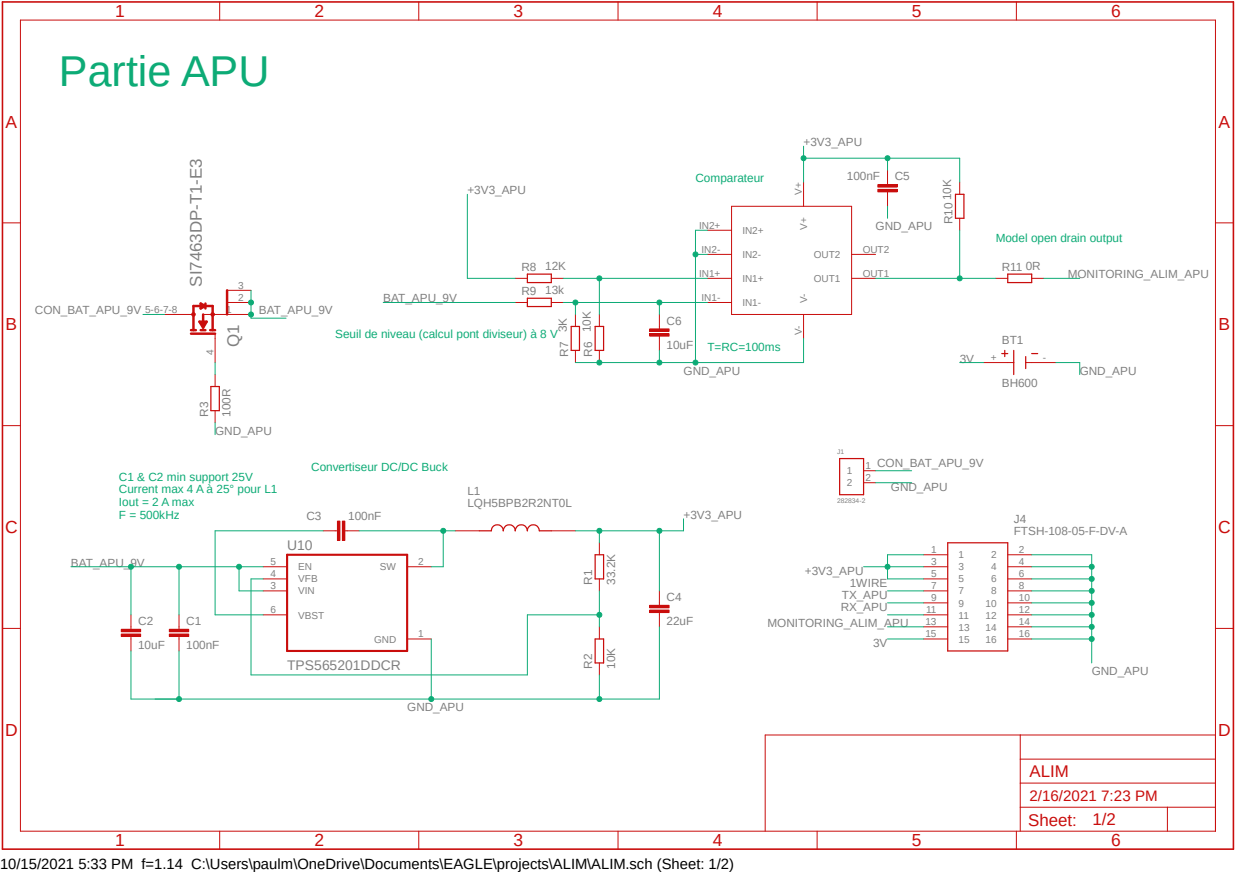
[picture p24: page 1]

Model open drain output

Seuil de niveau (calcul pont diviseur) à 8 V

Convertiseur DC/DC Buck

10/15/2021 5:33 PM f=1.14 C:\Users\paulm\OneDrive\Documents\EAGLE\projects\ALIM\ALIM.sch (Sheet: 1/2)

# 22uF ⁺³V³

A

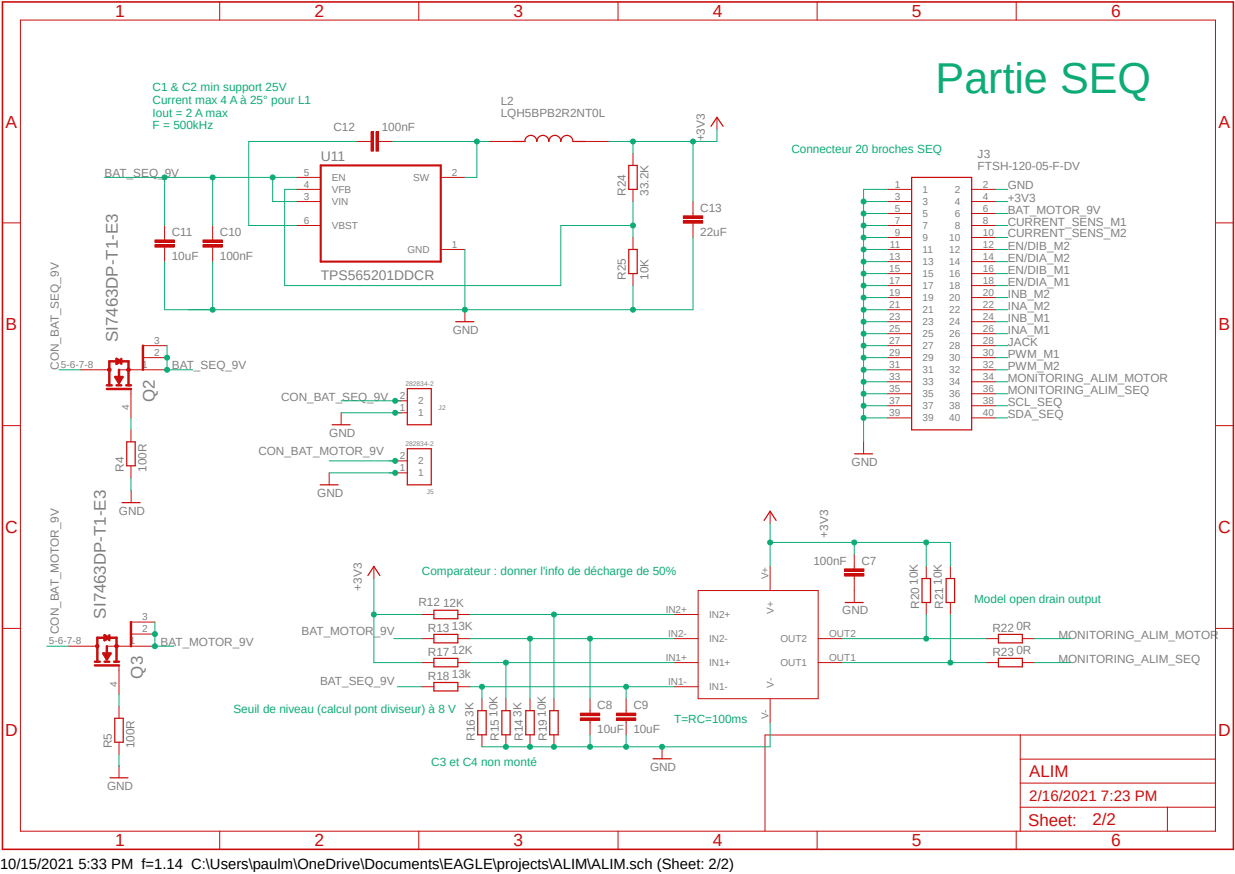
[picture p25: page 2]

Comparateur : donner l'info de décharge de 50%

Model open drain output

Seuil de niveau (calcul pont diviseur) à 8 V

10/15/2021 5:33 PM f=1.14 C:\Users\paulm\OneDrive\Documents\EAGLE\projects\ALIM\ALIM.sch (Sheet: 2/2)

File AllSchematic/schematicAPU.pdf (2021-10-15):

A

A

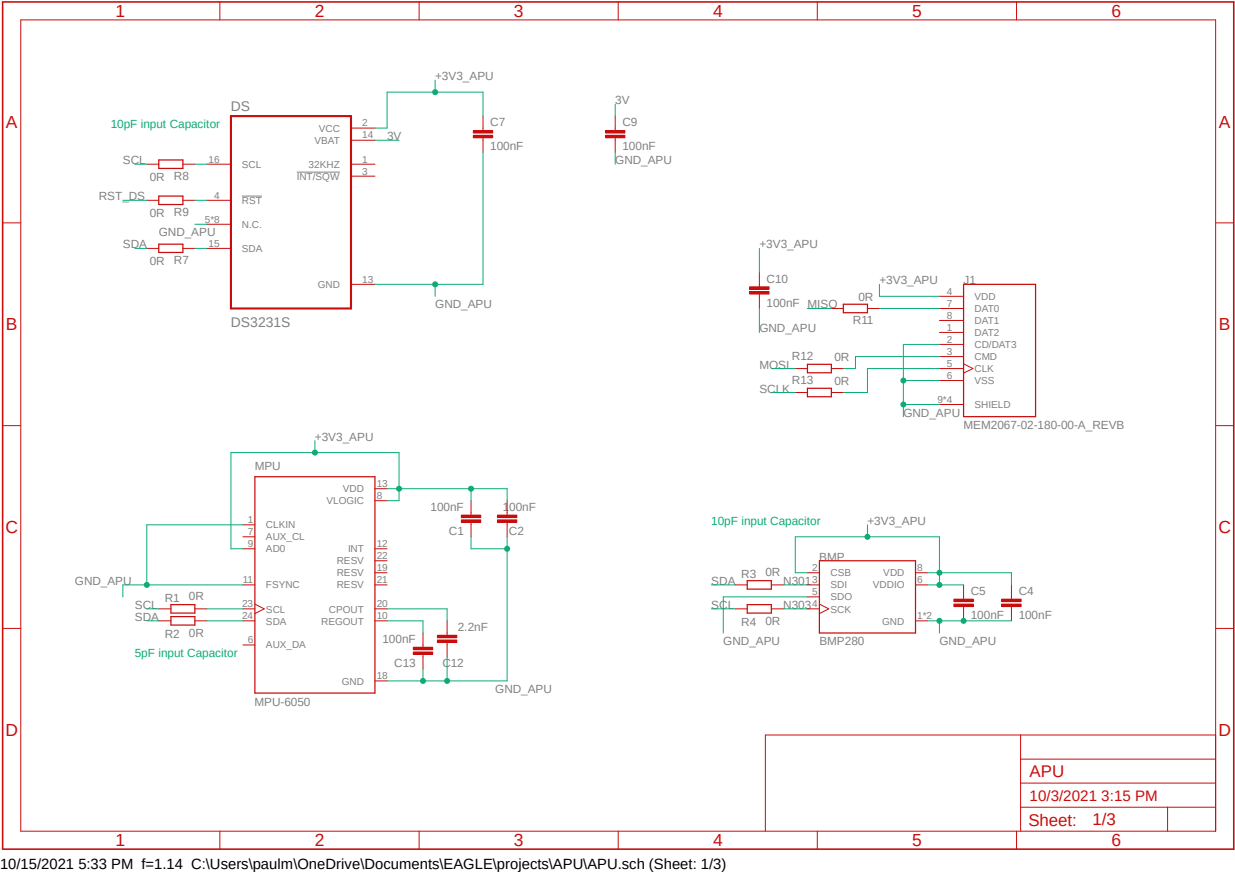
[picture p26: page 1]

10/15/2021 5:33 PM f=1.14 C:\Users\paulm\OneDrive\Documents\EAGLE\projects\APU\APU.sch (Sheet: 1/3)

A

A

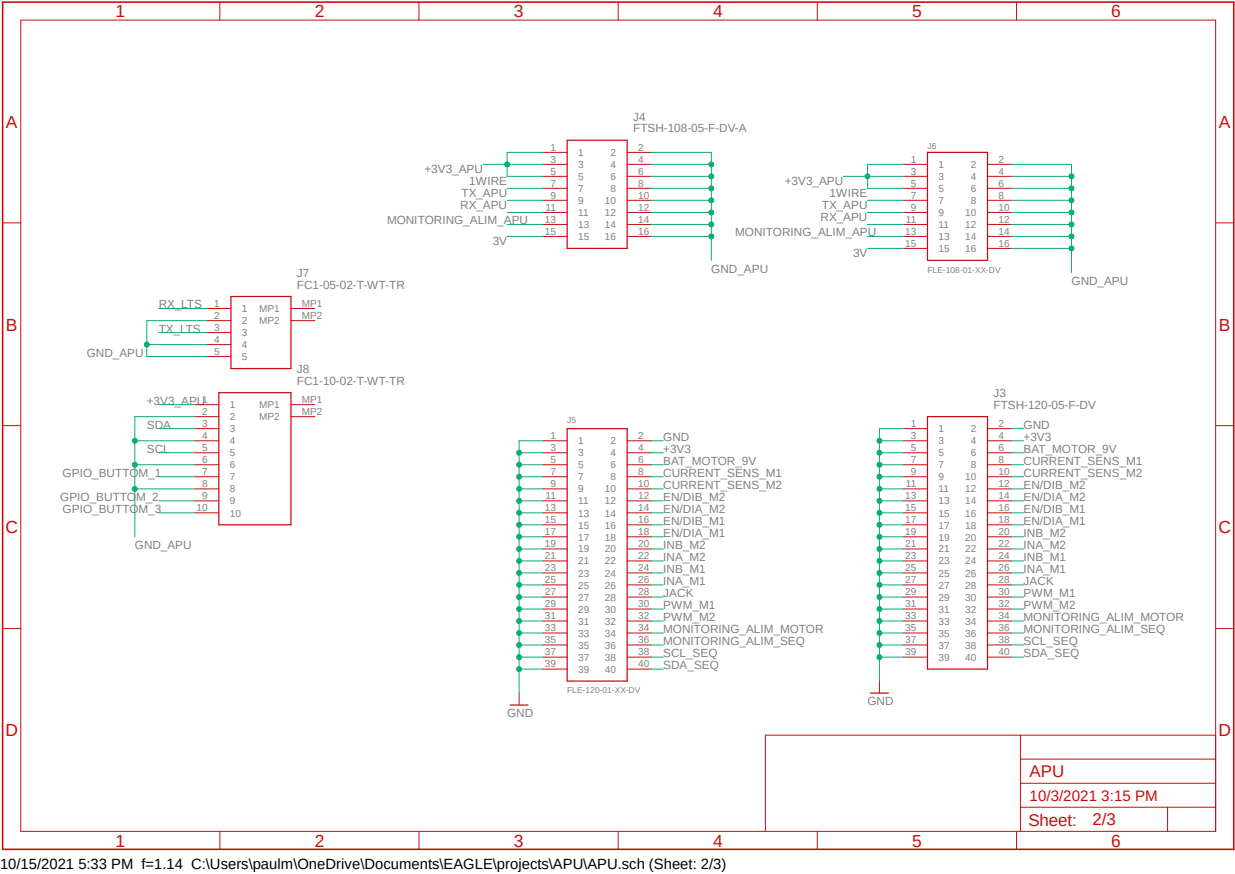
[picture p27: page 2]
FTSH-120-05-F-DV; GND; FTSH-108-05-F-DV-A; MONITORING_ALIM_APU; 1WIRE; +3V3_APU; RX_APU; TX_APU; GND_APU; INA_M1; INB_M1; PWM_M1; CURRENT_SENS_M1; INA_M2; INB_M2; PWM_M2; CURRENT_SENS_M2; EN/DIA_M1; EN/DIB_M1; EN/DIA_M2; EN/DIB_M2; JACK; MONITORING_ALIM_SEQ; MONITORING_ALIM_MOTOR; BAT_MOTOR_9V; SCL_SEQ; SDA_SEQ; SDA; SCL; TX_LTS; RX_LTS; GPIO_BUTTOM_1; GPIO_BUTTOM_2 GPIO_BUTTOM_3; APU

FLE-108-01-XX-DV FC1-05-02-T-WT-TR

FLE-120-01-XX-DV GND

10/15/2021 5:33 PM f=1.14 C:\Users\paulm\OneDrive\Documents\EAGLE\projects\APU\APU.sch (Sheet: 2/3)

## ASMT-RF45-AN002

D1

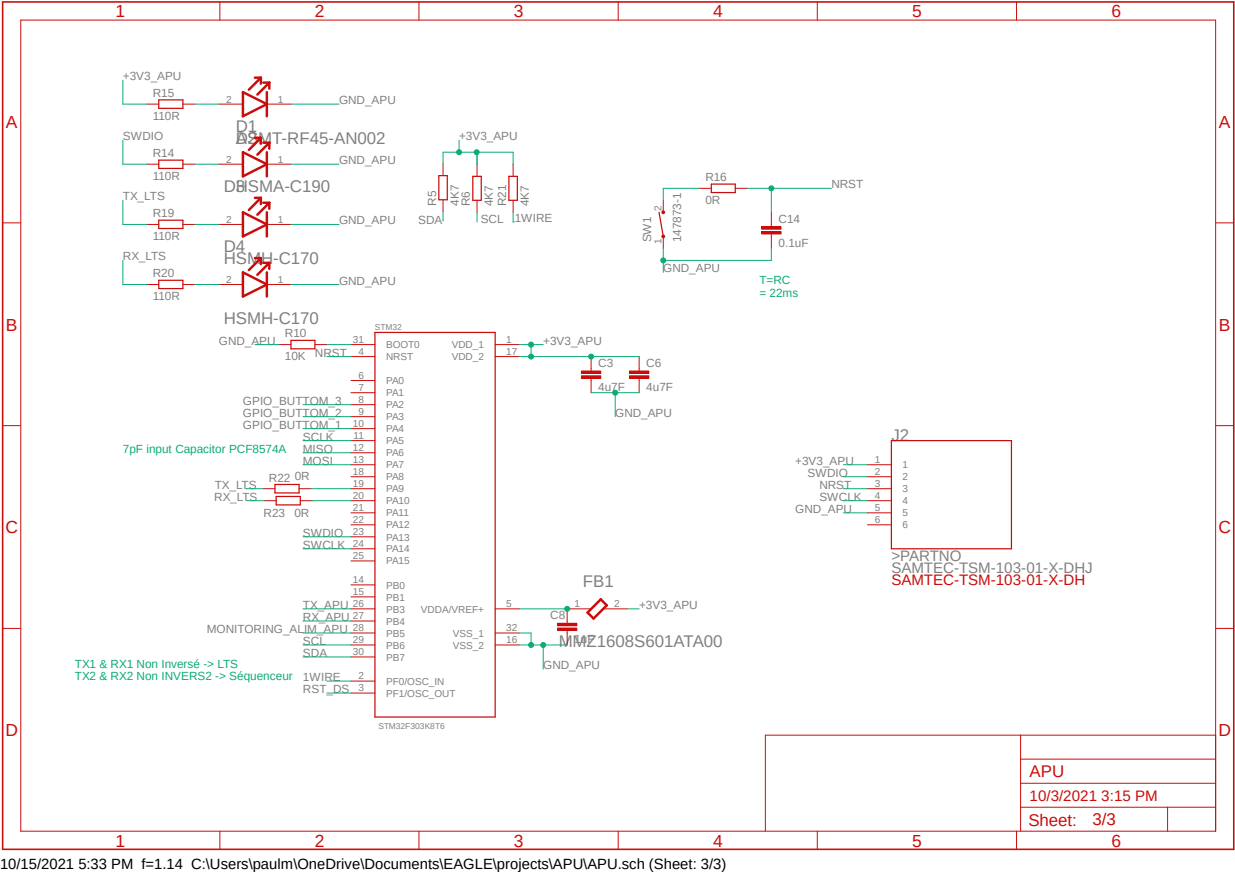
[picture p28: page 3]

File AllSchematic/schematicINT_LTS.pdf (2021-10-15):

A

A

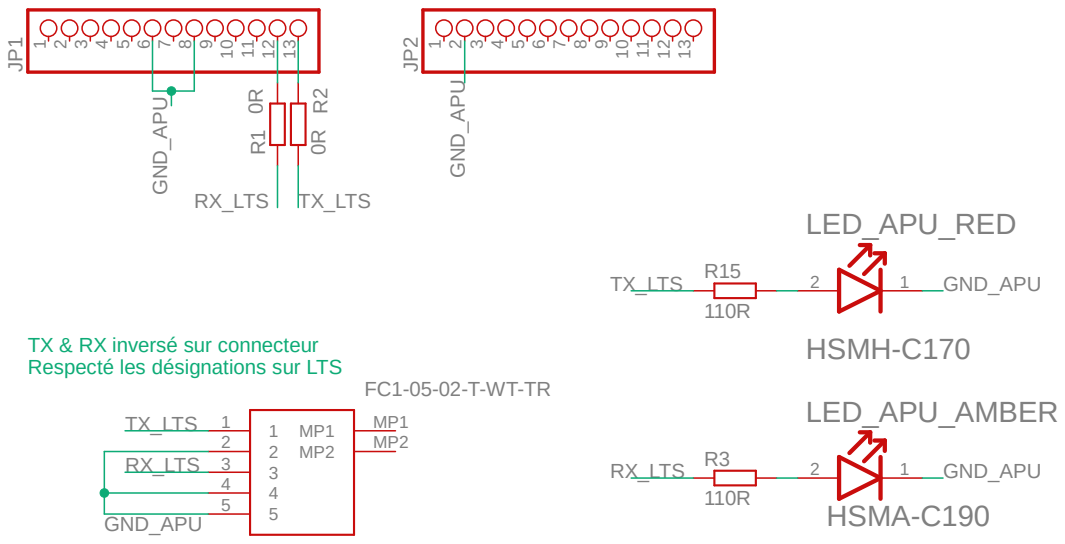
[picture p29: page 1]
HSMH-C170; LED_APU_RED; HSMA-C190; TX_LTS; LED_APU_AMBER; GND_APU GND_APU; GND_APU; RX_LTS; Sheet:; INT_LTS

TX & RX inversé sur connecteur
Respecté les désignations sur LTS

10/15/2021 5:34 PM f=1.14 C:\Users\paulm\OneDrive\Documents\EAGLE\projects\INT_LTS\INT_LTS.sch (Sheet: 1/1)

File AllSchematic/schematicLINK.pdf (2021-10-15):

A

A

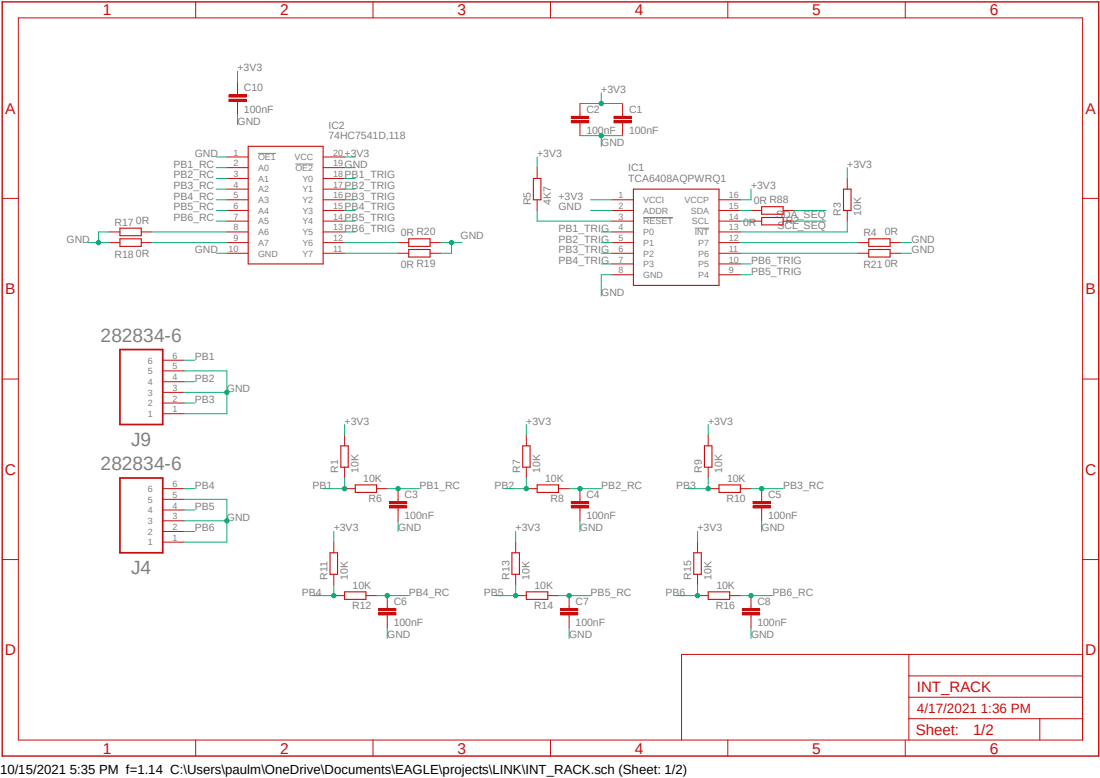
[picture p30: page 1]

10/15/2021 5:35 PM f=1.14 C:\Users\paulm\OneDrive\Documents\EAGLE\projects\LINK\INT_RACK.sch (Sheet: 1/2)

A

A

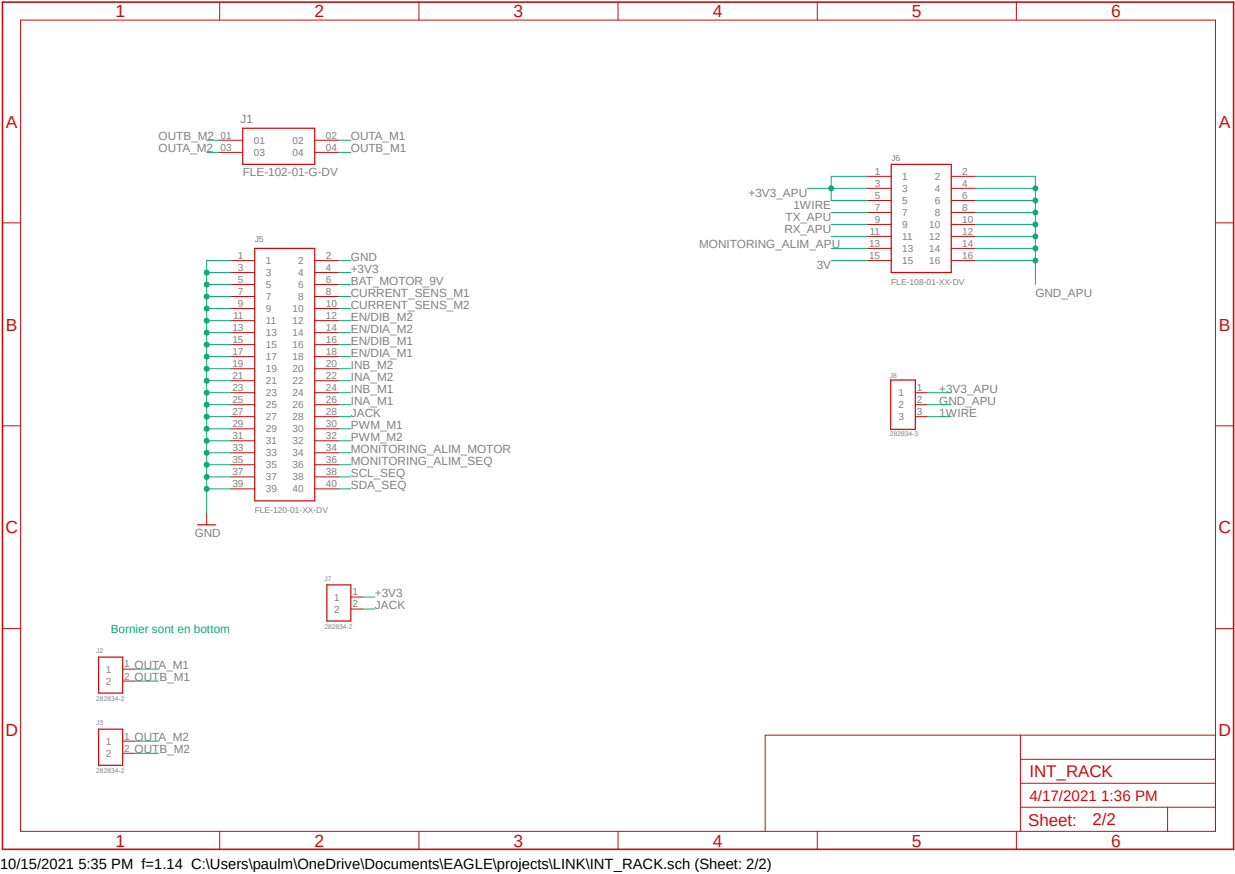
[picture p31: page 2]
GND_APU; OUTA_M1; OUTB_M1; INA_M1; INB_M1; PWM_M1; CURRENT_SENS_M1; INA_M2; INB_M2; PWM_M2; CURRENT_SENS_M2; OUTA_M2; OUTB_M2; EN/DIA_M1; EN/DIB_M1; EN/DIA_M2; EN/DIB_M2; JACK; MONITORING_ALIM_SEQ; MONITORING_ALIM_MOTOR; BAT_MOTOR_9V; SCL_SEQ SDA_SEQ; MONITORING_ALIM_APU; 1WIRE; +3V3_APU; RX_APU; TX_APU; GND; Sheet:; INT_RACK; Bornier sont en bottom

FLE-108-01-XX-DV FLE-102-01-G-DV

9 | 10 10

FLE-120-01-XX-DV GND

10/15/2021 5:35 PM f=1.14 C:\Users\paulm\OneDrive\Documents\EAGLE\projects\LINK\INT_RACK.sch (Sheet: 2/2)

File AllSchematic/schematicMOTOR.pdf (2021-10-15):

# GND 3K³ 3K³ ⁺³V³

A

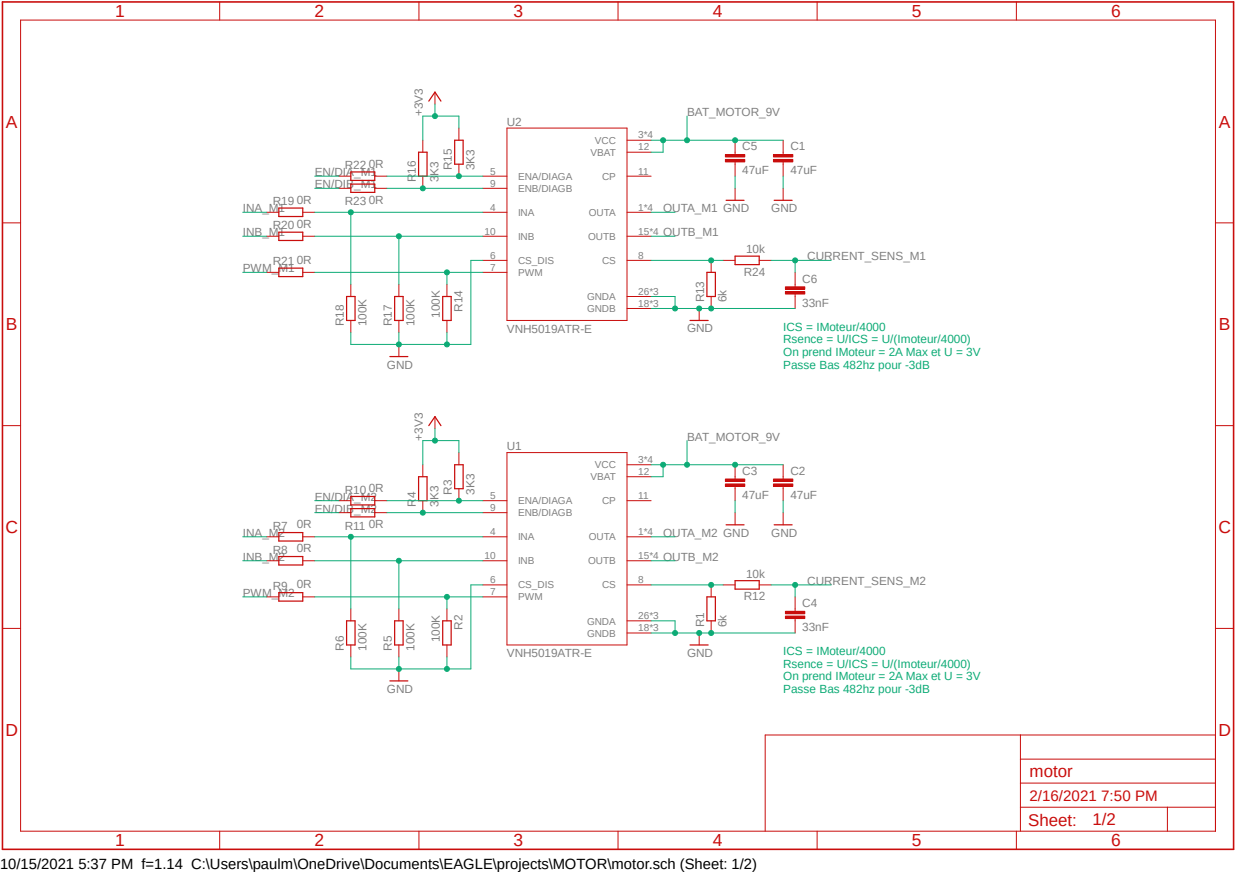
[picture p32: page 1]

ICS = IMoteur/4000
Rsence = U/ICS = U/(Imoteur/4000)
On prend IMoteur = 2A Max et U = 3V
Passe Bas 482hz pour -3dB

10/15/2021 5:37 PM f=1.14 C:\Users\paulm\OneDrive\Documents\EAGLE\projects\MOTOR\motor.sch (Sheet: 1/2)

A

A

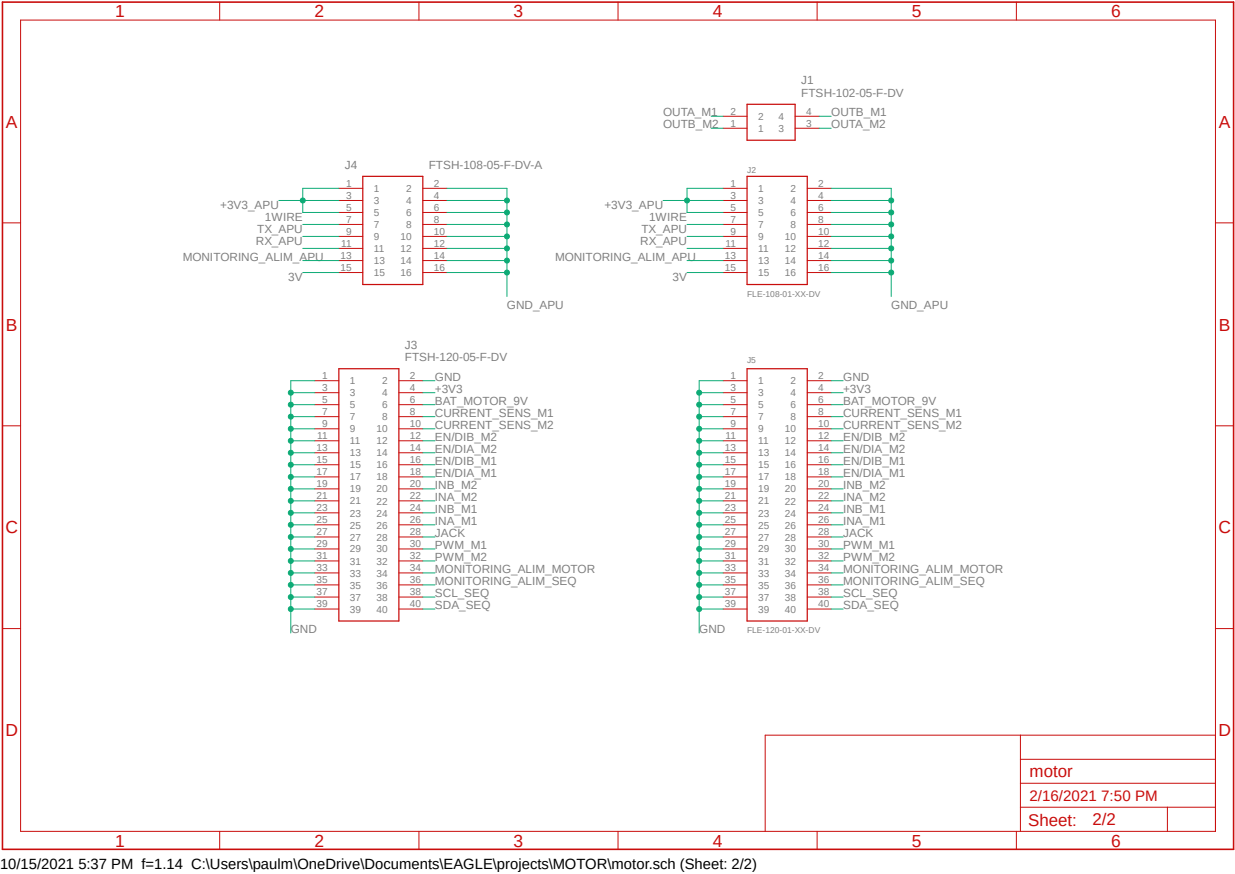
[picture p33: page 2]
FTSH-120-05-F-DV; FTSH-108-05-F-DV-A; FTSH-102-05-F-DV; GND; INA_M1; INB_M1; PWM_M1; CURRENT_SENS_M1; INA_M2; INB_M2; PWM_M2; CURRENT_SENS_M2; EN/DIA_M1; EN/DIB_M1; EN/DIA_M2; EN/DIB_M2; JACK; MONITORING_ALIM_SEQ; MONITORING_ALIM_MOTOR; BAT_MOTOR_9V; SCL_SEQ; SDA_SEQ; MONITORING_ALIM_APU; 1WIRE; +3V3_APU; RX_APU; TX_APU; GND_APU; OUTA_M1; OUTB_M2; OUTA_M2; OUTB_M1; Sheet:; motor

FLE-108-01-XX-DV

FLE-120-01-XX-DV

10/15/2021 5:37 PM f=1.14 C:\Users\paulm\OneDrive\Documents\EAGLE\projects\MOTOR\motor.sch (Sheet: 2/2)

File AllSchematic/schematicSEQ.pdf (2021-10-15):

# 0R 4K⁷ 4K⁷

A

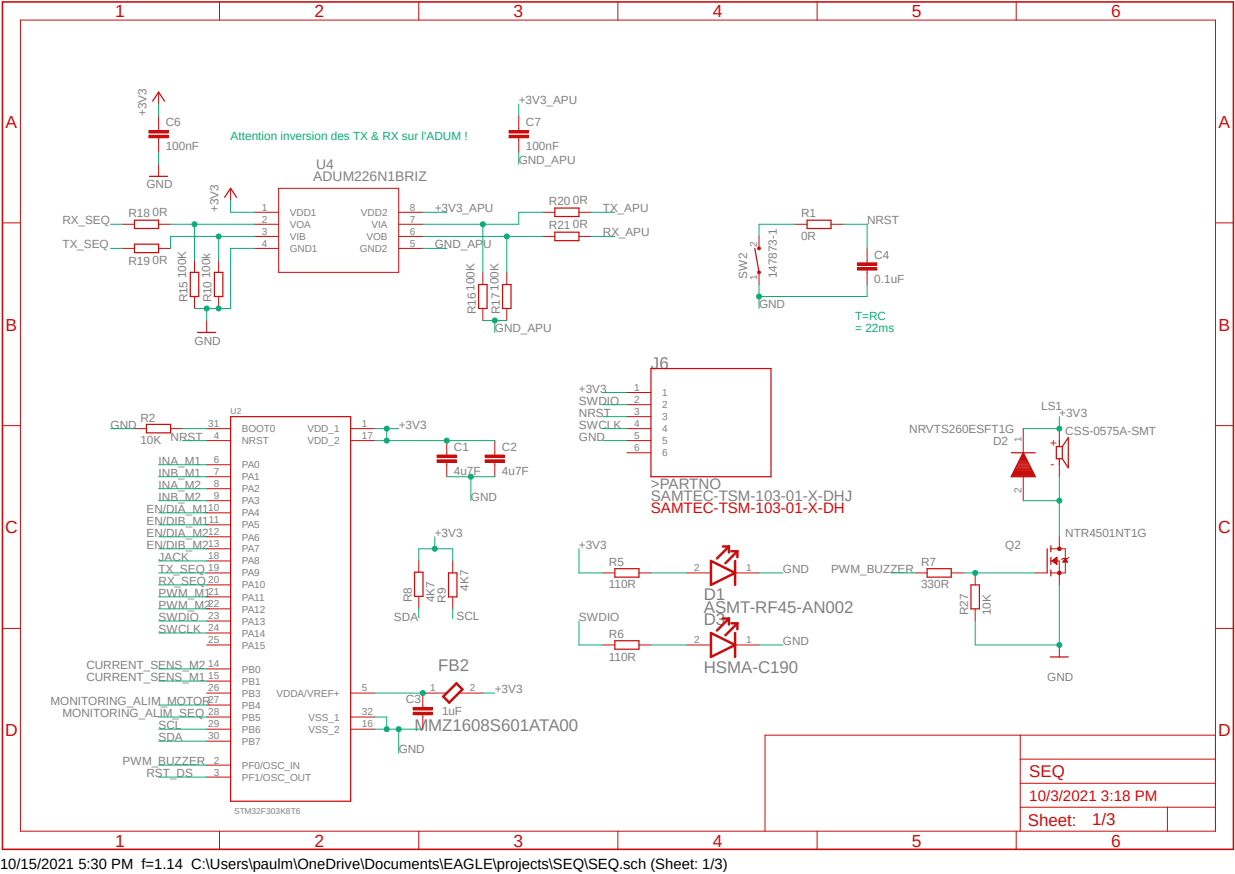
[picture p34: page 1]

Attention inversion des TX & RX sur l'ADUM !

10/15/2021 5:30 PM f=1.14 C:\Users\paulm\OneDrive\Documents\EAGLE\projects\SEQ\SEQ.sch (Sheet: 1/3)

## HSMH-C170

D4

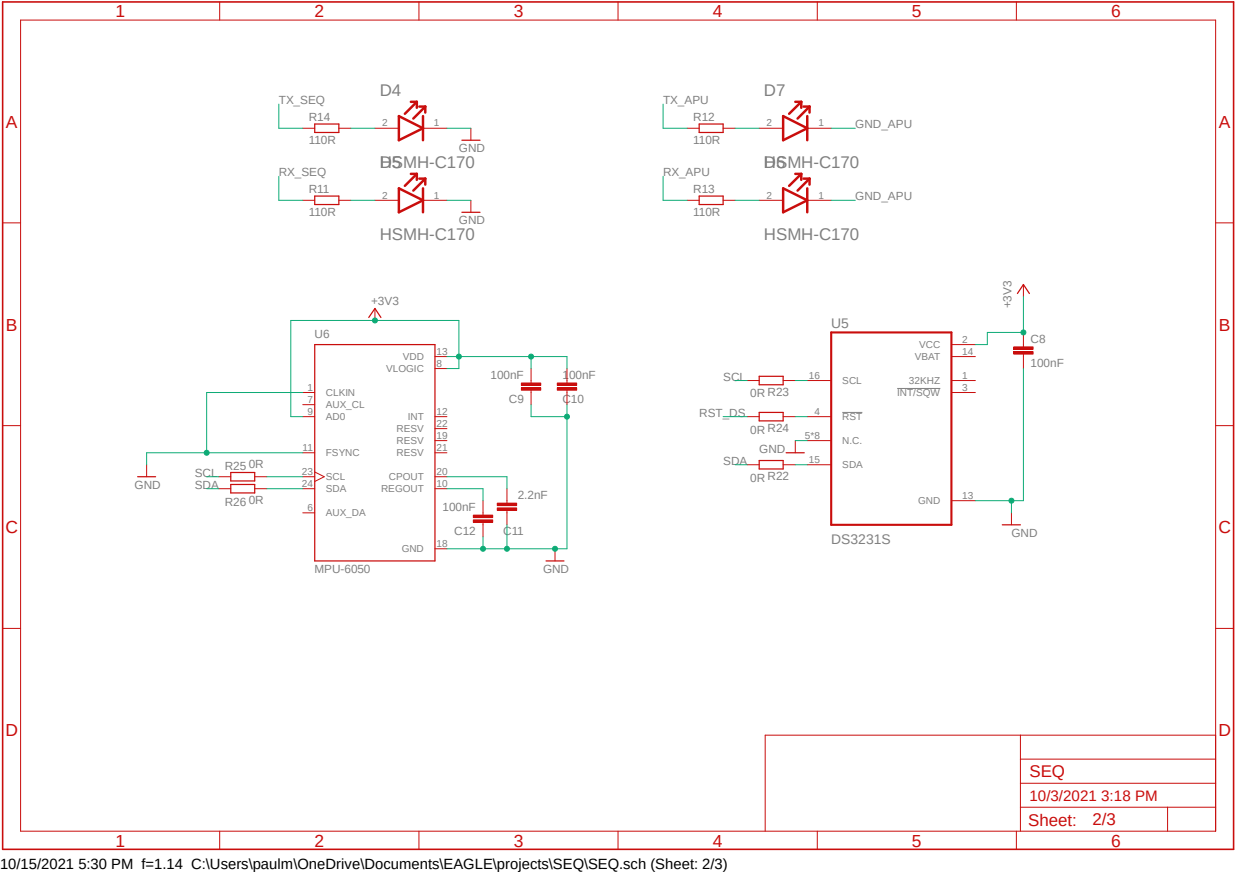
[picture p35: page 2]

10/15/2021 5:30 PM f=1.14 C:\Users\paulm\OneDrive\Documents\EAGLE\projects\SEQ\SEQ.sch (Sheet: 2/3)

A

A

FTSH-120-05-F-DV; GND; FTSH-108-05-F-DV-A; SCL; SDA; INA_M1; INB_M1; PWM_M1; CURRENT_SENS_M1; INA_M2; INB_M2; PWM_M2; CURRENT_SENS_M2; EN/DIA_M1; EN/DIB_M1; EN/DIA_M2; EN/DIB_M2; JACK; MONITORING_ALIM_SEQ; MONITORING_ALIM_MOTOR; BAT_MOTOR_9V; GND_APU; RX_APU; TX_APU; MONITORING_ALIM_APU; 1WIRE; +3V3_APU; SEQ

FLE-108-01-XX-DV 1

FLE-120-01-XX-DV GND

10/15/2021 5:30 PM f=1.14 C:\Users\paulm\OneDrive\Documents\EAGLE\projects\SEQ\SEQ.sch (Sheet: 3/3)

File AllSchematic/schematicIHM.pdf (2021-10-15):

## HSMH-C170

## LAR


10/15/2021 5:34 PM f=1.14 C:\Users\paulm\OneDrive\Documents\EAGLE\projects\IHM\IHM.sch (Sheet: 1/2)

A

A


10/15/2021 5:34 PM f=1.14 C:\Users\paulm\OneDrive\Documents\EAGLE\projects\IHM\IHM.sch (Sheet: 2/2) ¹⁴⁷⁸⁷³⁻¹ ¹⁰K

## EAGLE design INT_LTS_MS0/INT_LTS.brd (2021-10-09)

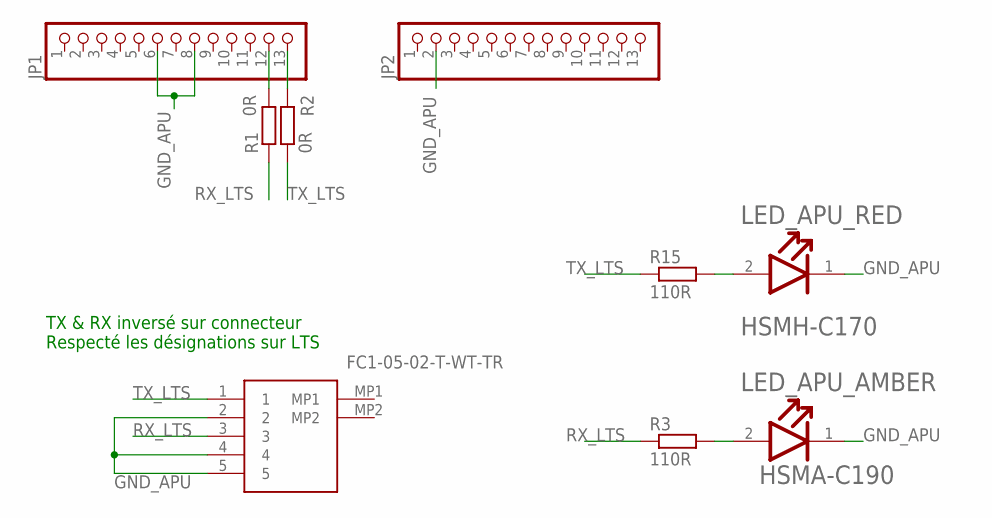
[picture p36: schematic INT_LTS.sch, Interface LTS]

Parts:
J7: FC1-05-02-T-WT-TR; FC10502TWTTR
JP1, JP2: PINHD-1X13; 1X13
LED_APU_AMBER: BROADCOM_HSMA-C190BROADCOM_HSMA-C190_0_0; BROADCOM_HSMA-C190_0
LED_APU_RED: BROADCOM_HSMH-C170BROADCOM_HSMH-C170_0_0; BROADCOM_HSMH-C170_0
R1, R2: 0R; R0603
R3, R15: 110R; R0603

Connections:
GND_APU: J7.2, J7.4, J7.5, JP1.6, JP1.8, JP2.2, LED_APU_AMBER.1 (CATHODE), LED_APU_RED.1 (CATHODE)
unnamed: JP1.12, R1.2
unnamed: JP1.13, R2.2
unnamed: LED_APU_AMBER.2 (ANODE), R3.2
unnamed: LED_APU_RED.2 (ANODE), R15.2
RX_LTS: J7.3, R1.1, R3.1
TX_LTS: J7.1, R2.1, R15.1

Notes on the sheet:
TX & RX inversé sur connecteur Respecté les désignations sur LTS

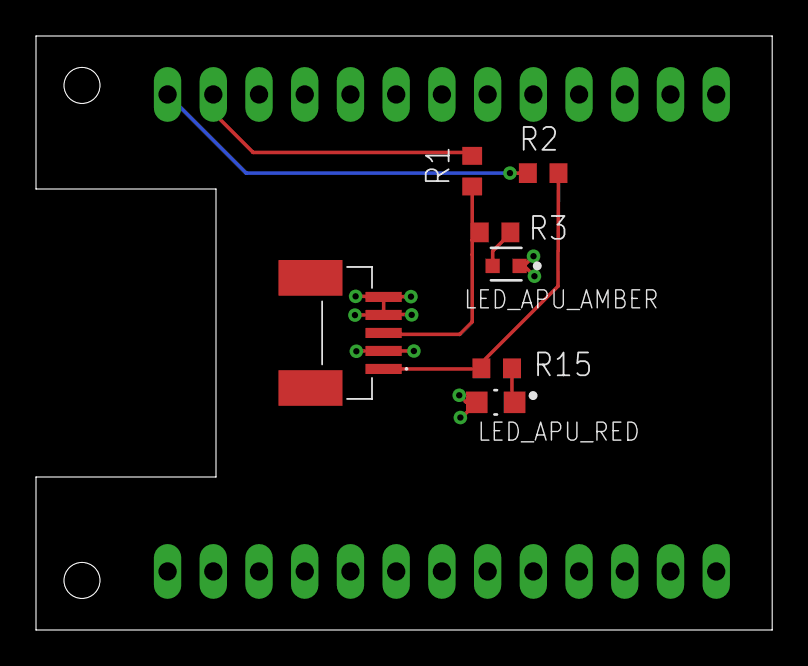
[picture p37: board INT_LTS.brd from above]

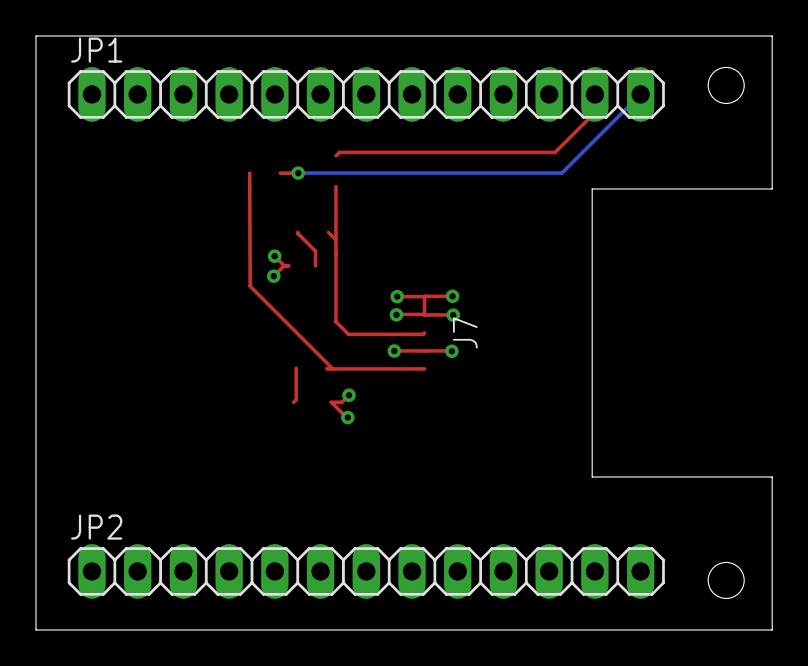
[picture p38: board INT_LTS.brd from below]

Board: 2 copper layers, 40.9 x 33.0 mm, 9 parts (2 on the bottom side), 7 nets.

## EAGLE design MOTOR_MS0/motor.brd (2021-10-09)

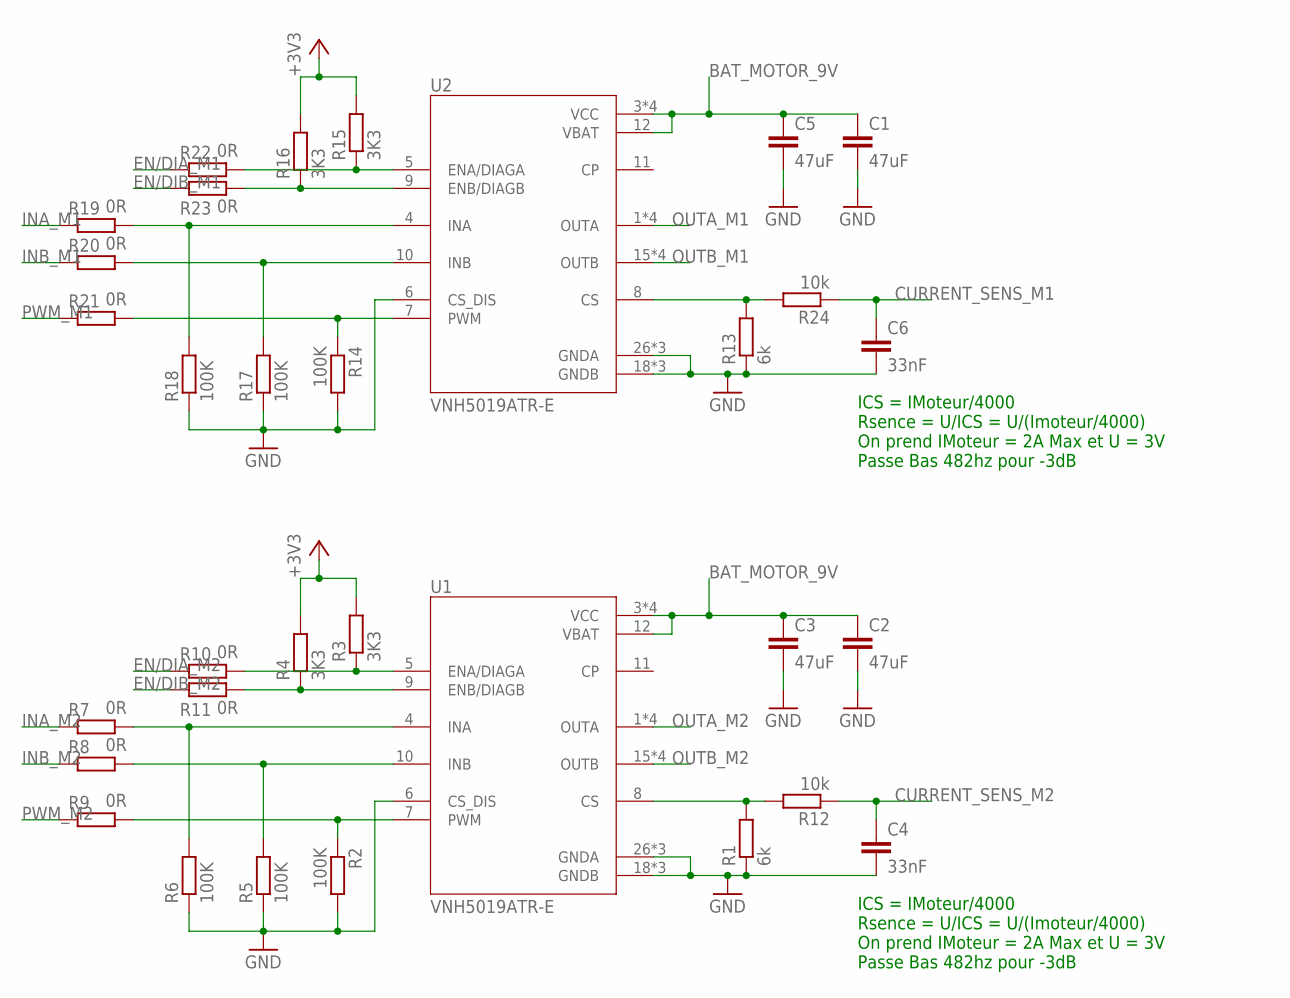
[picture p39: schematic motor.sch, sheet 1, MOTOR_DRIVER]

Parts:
C1, C2, C3, C5: 47uF; C0805
C4, C6: 33nF; C0805
R1, R13: 6k; R0603
R2, R5, R6, R14, R17, R18: 100K; R0603
R3, R4, R15, R16: 3K3; R0603
R7, R8, R9, R10, R11, R19, R20, R21, R22, R23: 0R; R0603
R12, R24: 10k; R0603
U1, U2: VNH5019ATR-E; IC_VNH5019ATR-E

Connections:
+3V3: R3.2, R4.2, R15.2, R16.2; also elsewhere on the board
BAT_MOTOR_9V: C1.1, C2.1, C3.1, C5.1, U1.3 (VCC), U1.12 (VBAT), U1.13 (VCC), U1.23 (VCC), U1.HS1 (VCC), U2.3 (VCC), U2.12 (VBAT), U2.13 (VCC), U2.23 (VCC), U2.HS1 (VCC); also elsewhere on the board
CURRENT_SENS_M1: C6.1, R24.1; also elsewhere on the board
CURRENT_SENS_M2: C4.1, R12.1; also elsewhere on the board
EN/DIA_M1: R22.1; also elsewhere on the board
EN/DIA_M2: R10.1; also elsewhere on the board
EN/DIB_M1: R23.1; also elsewhere on the board
EN/DIB_M2: R11.1; also elsewhere on the board
GND: C1.2, C2.2, C3.2, C4.2, C5.2, C6.2, R1.1, R2.2, R5.1, R6.1, R13.1, R14.2, R17.1, R18.1, U1.6 (CS_DIS), U1.18 (GNDB), U1.19 (GNDB), U1.20 (GNDB), U1.26 (GNDA), U1.27 (GNDA), U1.28 (GNDA), U2.6 (CS_DIS), U2.18 (GNDB), U2.19 (GNDB), U2.20 (GNDB), U2.26 (GNDA), U2.27 (GNDA), U2.28 (GNDA); also elsewhere on the board
INA_M1: R19.1; also elsewhere on the board
INA_M2: R7.1; also elsewhere on the board
INB_M1: R20.1; also elsewhere on the board
INB_M2: R8.1; also elsewhere on the board
unnamed: R1.2, R12.2, U1.8 (CS)
unnamed: R3.1, R10.2, U1.5 (ENA/DIAGA)
unnamed: R4.1, R11.2, U1.9 (ENB/DIAGB)
unnamed: R2.1, R9.2, U1.7 (PWM)
unnamed: R5.2, R8.2, U1.10 (INB)
unnamed: R6.2, R7.2, U1.4 (INA)
unnamed: R13.2, R24.2, U2.8 (CS)
unnamed: R15.1, R22.2, U2.5 (ENA/DIAGA)
unnamed: R16.1, R23.2, U2.9 (ENB/DIAGB)
unnamed: R14.1, R21.2, U2.7 (PWM)
unnamed: R17.2, R20.2, U2.10 (INB)
unnamed: R18.2, R19.2, U2.4 (INA)
OUTA_M1: U2.1 (OUTA), U2.25 (OUTA), U2.30 (OUTA), U2.HS2 (OUTA); also elsewhere on the board
OUTA_M2: U1.1 (OUTA), U1.25 (OUTA), U1.30 (OUTA), U1.HS2 (OUTA); also elsewhere on the board
OUTB_M1: U2.15 (OUTB), U2.16 (OUTB), U2.21 (OUTB), U2.HS3 (OUTB); also elsewhere on the board
OUTB_M2: U1.15 (OUTB), U1.16 (OUTB), U1.21 (OUTB), U1.HS3 (OUTB); also elsewhere on the board
PWM_M1: R21.1; also elsewhere on the board
PWM_M2: R9.1; also elsewhere on the board

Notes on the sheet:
ICS = IMoteur/4000 Rsence = U/ICS = U/(Imoteur/4000) On prend IMoteur = 2A Max et U = 3V Passe Bas 482hz pour -3dB

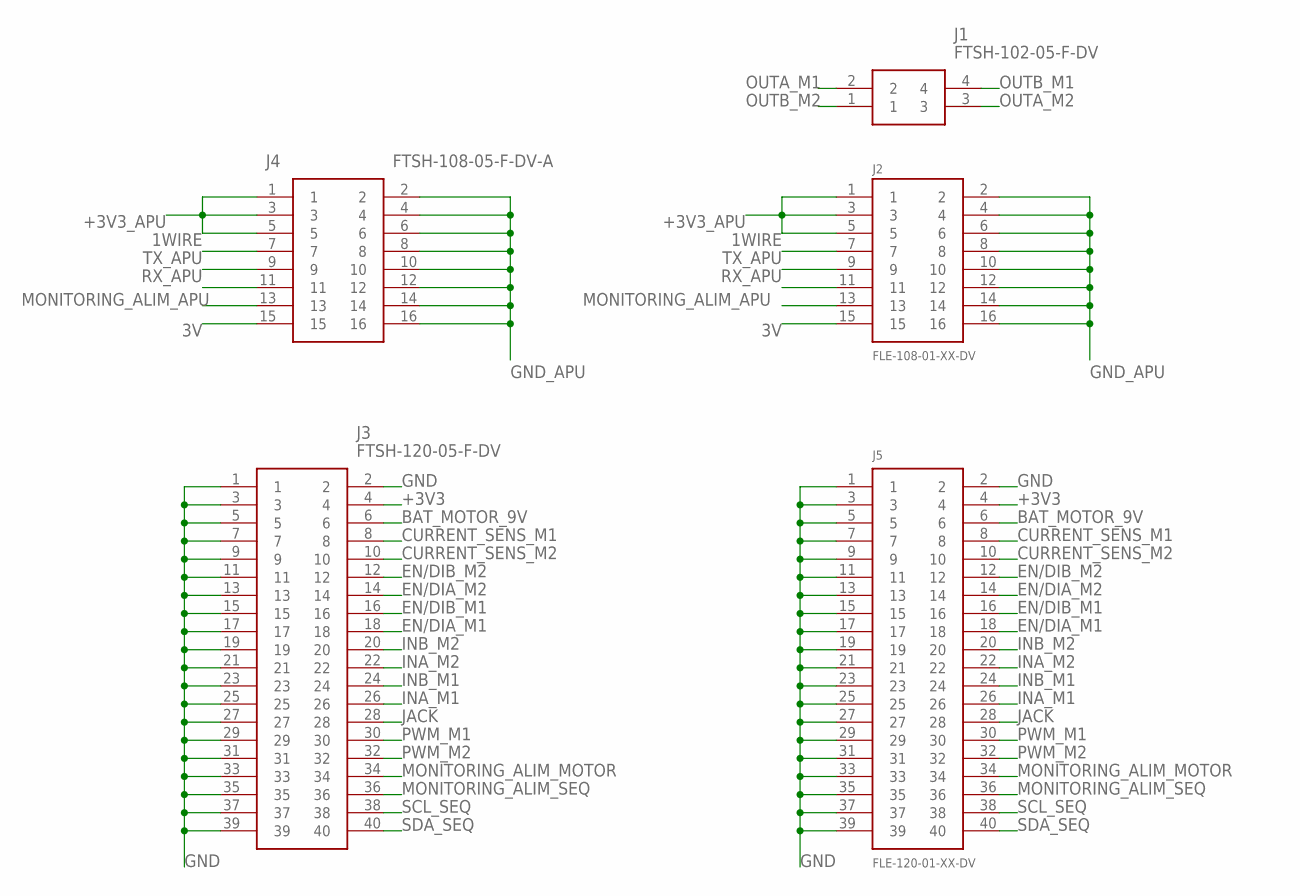
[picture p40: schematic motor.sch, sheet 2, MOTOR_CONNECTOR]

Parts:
J1: FTSH-102-05-F-DV; FTSH-102-XX-YYY-DV
J2: FLE-108-01-XX-DV
J3: FTSH-120-05-F-DV; FTSH-120-XX-YYY-DV
J4: FTSH-108-05-F-DV-A; FTSH-108-XX-YYY-DV-A
J5: FLE-120-01-XX-DV

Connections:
1WIRE: J2.7, J4.7
3V: J2.15, J4.15
+3V3: J3.4, J5.4; also elsewhere on the board
+3V3_APU: J2.1, J2.3, J2.5, J4.1, J4.3, J4.5
BAT_MOTOR_9V: J3.6, J5.6; also elsewhere on the board
CURRENT_SENS_M1: J3.8, J5.8; also elsewhere on the board
CURRENT_SENS_M2: J3.10, J5.10; also elsewhere on the board
EN/DIA_M1: J3.18, J5.18; also elsewhere on the board
EN/DIA_M2: J3.14, J5.14; also elsewhere on the board
EN/DIB_M1: J3.16, J5.16; also elsewhere on the board
EN/DIB_M2: J3.12, J5.12; also elsewhere on the board
GND: J3.1, J3.2, J3.3, J3.5, J3.7, J3.9, J3.11, J3.13, J3.15, J3.17, J3.19, J3.21, J3.23, J3.25, J3.27, J3.29, J3.31, J3.33, J3.35, J3.37, J3.39, J5.1, J5.2, J5.3, J5.5, J5.7, J5.9, J5.11, J5.13, J5.15, J5.17, J5.19, J5.21, J5.23, J5.25, J5.27, J5.29, J5.31, J5.33, J5.35, J5.37, J5.39; also elsewhere on the board
GND_APU: J2.2, J2.4, J2.6, J2.8, J2.10, J2.12, J2.14, J2.16, J4.2, J4.4, J4.6, J4.8, J4.10, J4.12, J4.14, J4.16
INA_M1: J3.26, J5.26; also elsewhere on the board
INA_M2: J3.22, J5.22; also elsewhere on the board
INB_M1: J3.24, J5.24; also elsewhere on the board
INB_M2: J3.20, J5.20; also elsewhere on the board
JACK: J3.28, J5.28
MONITORING_ALIM_APU: J2.13, J4.13
MONITORING_ALIM_MOTOR: J3.34, J5.34
MONITORING_ALIM_SEQ: J3.36, J5.36
OUTA_M1: J1.2; also elsewhere on the board
OUTA_M2: J1.3; also elsewhere on the board
OUTB_M1: J1.4; also elsewhere on the board
OUTB_M2: J1.1; also elsewhere on the board
PWM_M1: J3.30, J5.30; also elsewhere on the board
PWM_M2: J3.32, J5.32; also elsewhere on the board
RX_APU: J2.11, J4.11
SCL_SEQ: J3.38, J5.38
SDA_SEQ: J3.40, J5.40
TX_APU: J2.9, J4.9

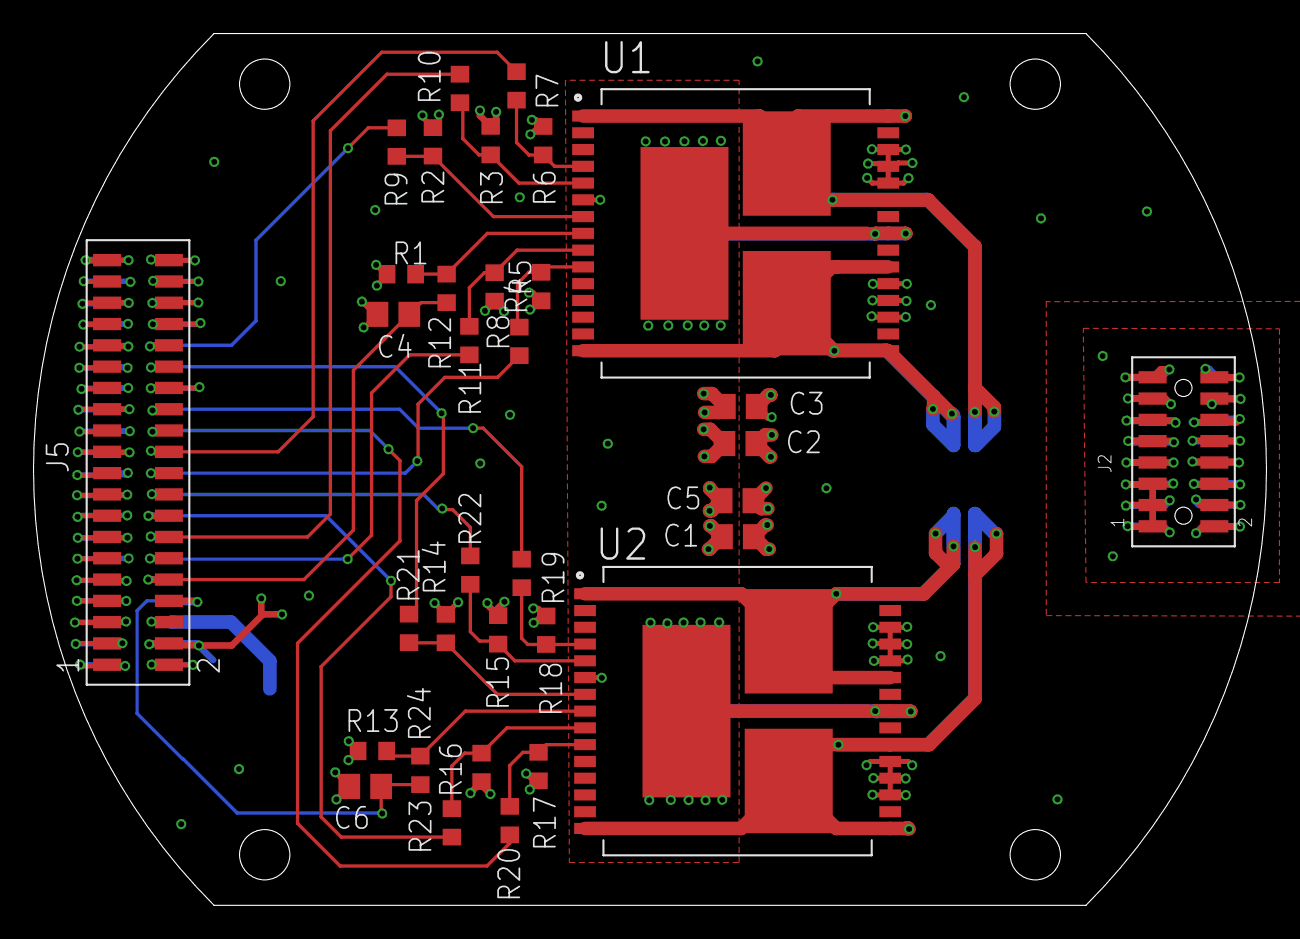
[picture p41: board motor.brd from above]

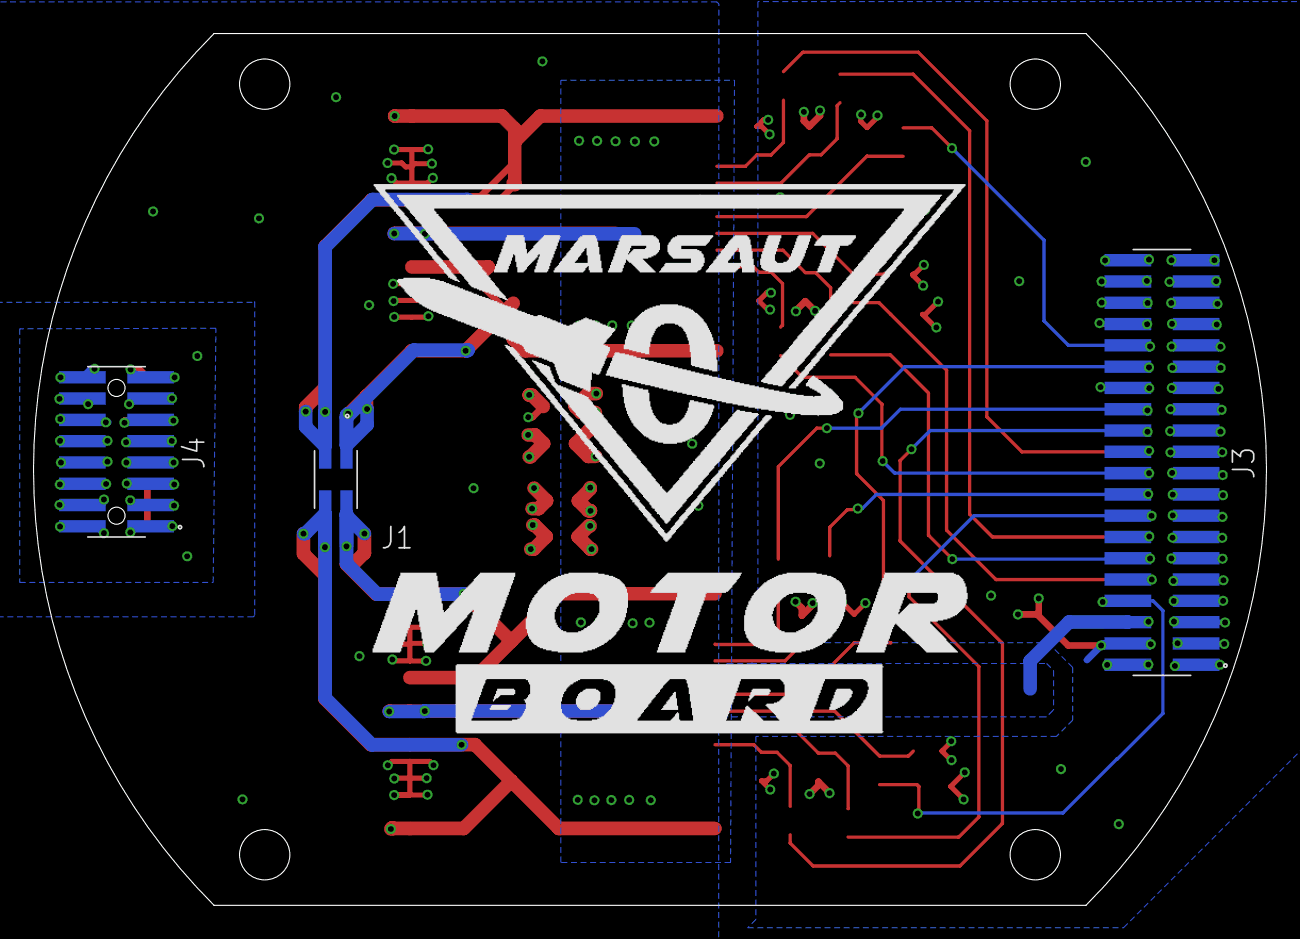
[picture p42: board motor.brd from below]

Board: 4 copper layers, 73.5 x 52.0 mm, 37 parts (3 on the bottom side), 43 nets.

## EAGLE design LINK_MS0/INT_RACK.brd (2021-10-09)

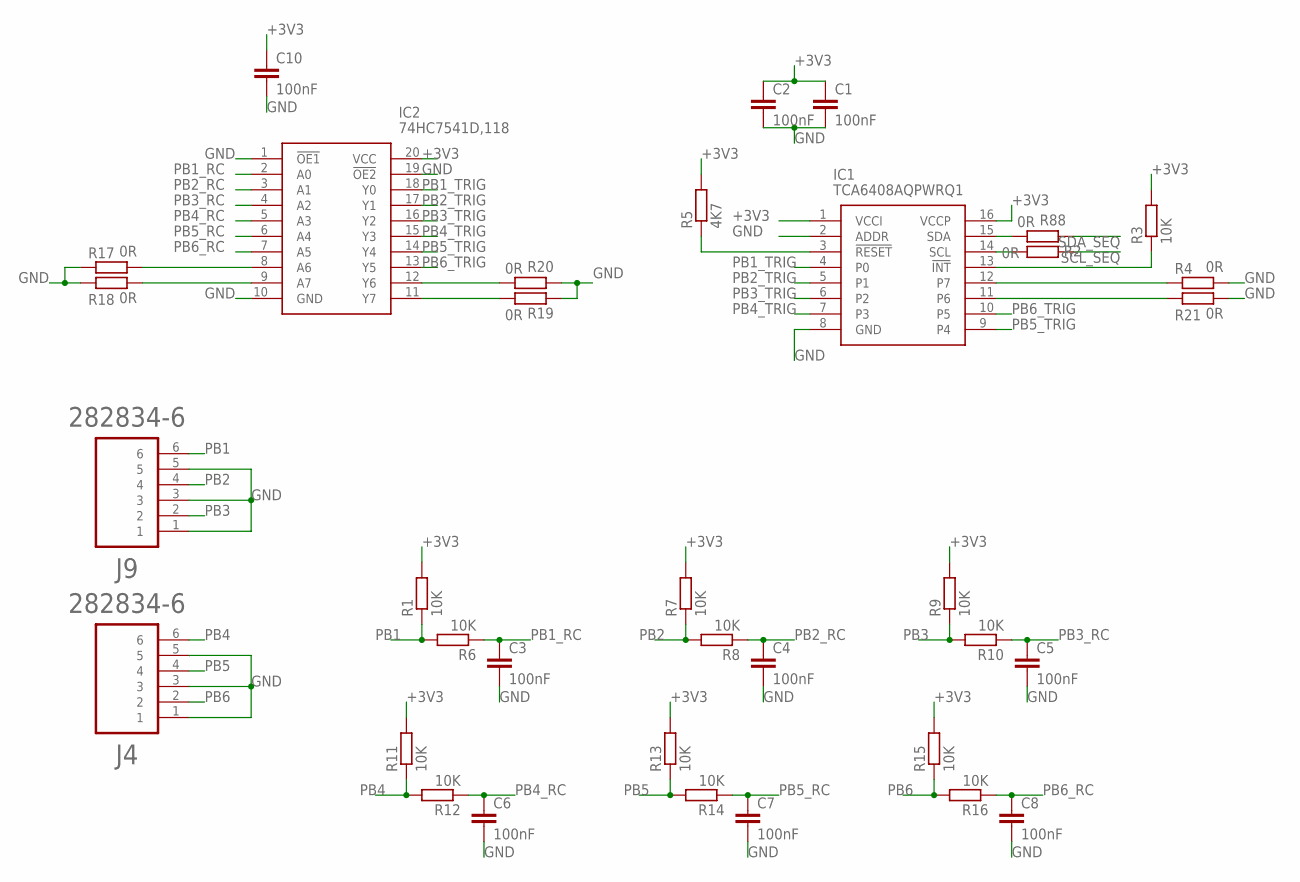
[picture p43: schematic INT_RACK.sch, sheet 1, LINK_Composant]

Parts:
C1, C2, C3, C4, C5, C6, C7, C8, C10: 100nF; C0805
IC1: TCA6408AQPWRQ1; SOP65P640X120-16N
IC2: 74HC7541D,118; SOIC127P1032X265-20N
J4, J9: 282834-6; TE_282834-6
R1, R3, R6, R7, R8, R9, R10, R11, R12, R13, R14, R15, R16: 10K; R0603
R2, R4, R17, R18, R19, R20, R21, R88: 0R; R0603
R5: 4K7; R0603

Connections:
+3V3: C1.1, C2.1, C10.1, IC1.1 (VCCI), IC1.16 (VCCP), IC2.20 (VCC), R1.2, R3.2, R5.2, R7.2, R9.2, R11.2, R13.2, R15.2; also elsewhere on the board
GND: C1.2, C2.2, C3.2, C4.2, C5.2, C6.2, C7.2, C8.2, C10.2, IC1.2 (ADDR), IC1.8 (GND), IC2.1 (!OE1), IC2.10 (GND), IC2.19 (!OE2), J4.1, J4.3, J4.5, J9.1, J9.3, J9.5, R4.2, R17.1, R18.1, R19.1, R20.1, R21.2; also elsewhere on the board
unnamed: IC1.11 (P6), R21.1
unnamed: IC1.14 (SCL), R2.2
unnamed: IC1.13 (!INT), R3.1
unnamed: IC1.12 (P7), R4.1
unnamed: IC1.3 (!RESET), R5.1
unnamed: IC2.12 (Y6), R20.2
unnamed: IC2.11 (Y7), R19.2
unnamed: IC2.8 (A6), R17.2
unnamed: IC2.9 (A7), R18.2
unnamed: IC1.15 (SDA), R88.2
PB1: J9.6, R1.1, R6.2
PB1_RC: C3.1, IC2.2 (A0), R6.1
PB1_TRIG: IC1.4 (P0), IC2.18 (Y0)
PB2: J9.4, R7.1, R8.2
PB2_RC: C4.1, IC2.3 (A1), R8.1
PB2_TRIG: IC1.5 (P1), IC2.17 (Y1)
PB3: J9.2, R9.1, R10.2
PB3_RC: C5.1, IC2.4 (A2), R10.1
PB3_TRIG: IC1.6 (P2), IC2.16 (Y2)
PB4: J4.6, R11.1, R12.2
PB4_RC: C6.1, IC2.5 (A3), R12.1
PB4_TRIG: IC1.7 (P3), IC2.15 (Y3)
PB5: J4.4, R13.1, R14.2
PB5_RC: C7.1, IC2.6 (A4), R14.1
PB5_TRIG: IC1.9 (P4), IC2.14 (Y4)
PB6: J4.2, R15.1, R16.2
PB6_RC: C8.1, IC2.7 (A5), R16.1
PB6_TRIG: IC1.10 (P5), IC2.13 (Y5)
SCL_SEQ: R2.1; also elsewhere on the board
SDA_SEQ: R88.1; also elsewhere on the board

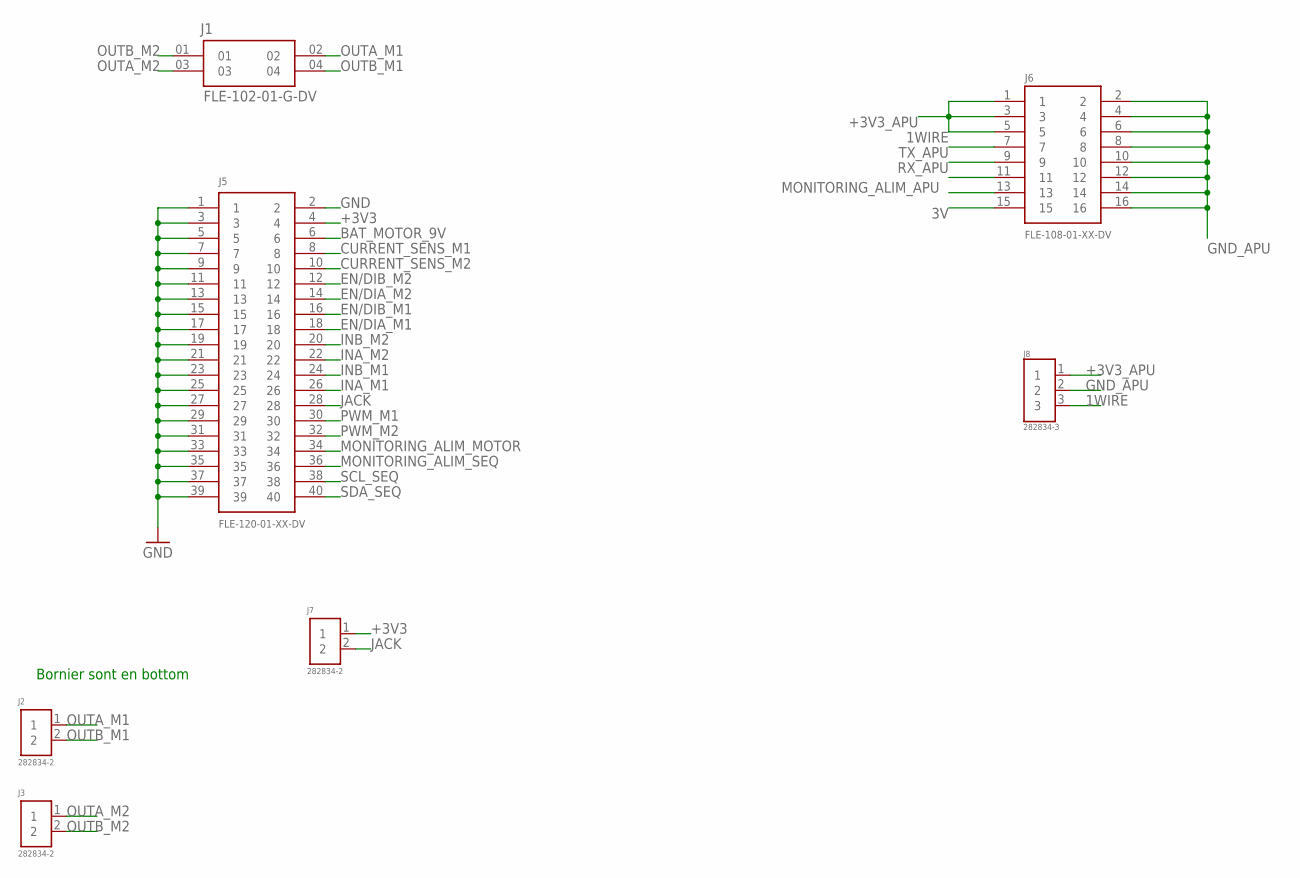
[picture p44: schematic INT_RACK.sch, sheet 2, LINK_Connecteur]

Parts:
J1: FLE-102-01-G-DV; SAMTEC_FLE-102-01-G-DV
J2, J3, J7: 282834-2; CONN_282834-2
J5: FLE-120-01-XX-DV
J6: FLE-108-01-XX-DV
J8: 282834-3; TE_282834-3

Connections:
1WIRE: J6.7, J8.3
3V: J6.15
+3V3: J5.4, J7.1; also elsewhere on the board
+3V3_APU: J6.1, J6.3, J6.5, J8.1
BAT_MOTOR_9V: J5.6
CURRENT_SENS_M1: J5.8
CURRENT_SENS_M2: J5.10
EN/DIA_M1: J5.18
EN/DIA_M2: J5.14
EN/DIB_M1: J5.16
EN/DIB_M2: J5.12
GND: J5.1, J5.2, J5.3, J5.5, J5.7, J5.9, J5.11, J5.13, J5.15, J5.17, J5.19, J5.21, J5.23, J5.25, J5.27, J5.29, J5.31, J5.33, J5.35, J5.37, J5.39; also elsewhere on the board
GND_APU: J6.2, J6.4, J6.6, J6.8, J6.10, J6.12, J6.14, J6.16, J8.2
INA_M1: J5.26
INA_M2: J5.22
INB_M1: J5.24
INB_M2: J5.20
JACK: J5.28, J7.2
MONITORING_ALIM_APU: J6.13
MONITORING_ALIM_MOTOR: J5.34
MONITORING_ALIM_SEQ: J5.36
OUTA_M1: J1.02, J2.1
OUTA_M2: J1.03, J3.1
OUTB_M1: J1.04, J2.2
OUTB_M2: J1.01, J3.2
PWM_M1: J5.30
PWM_M2: J5.32
RX_APU: J6.11
SCL_SEQ: J5.38; also elsewhere on the board
SDA_SEQ: J5.40; also elsewhere on the board
TX_APU: J6.9

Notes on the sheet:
Bornier sont en bottom

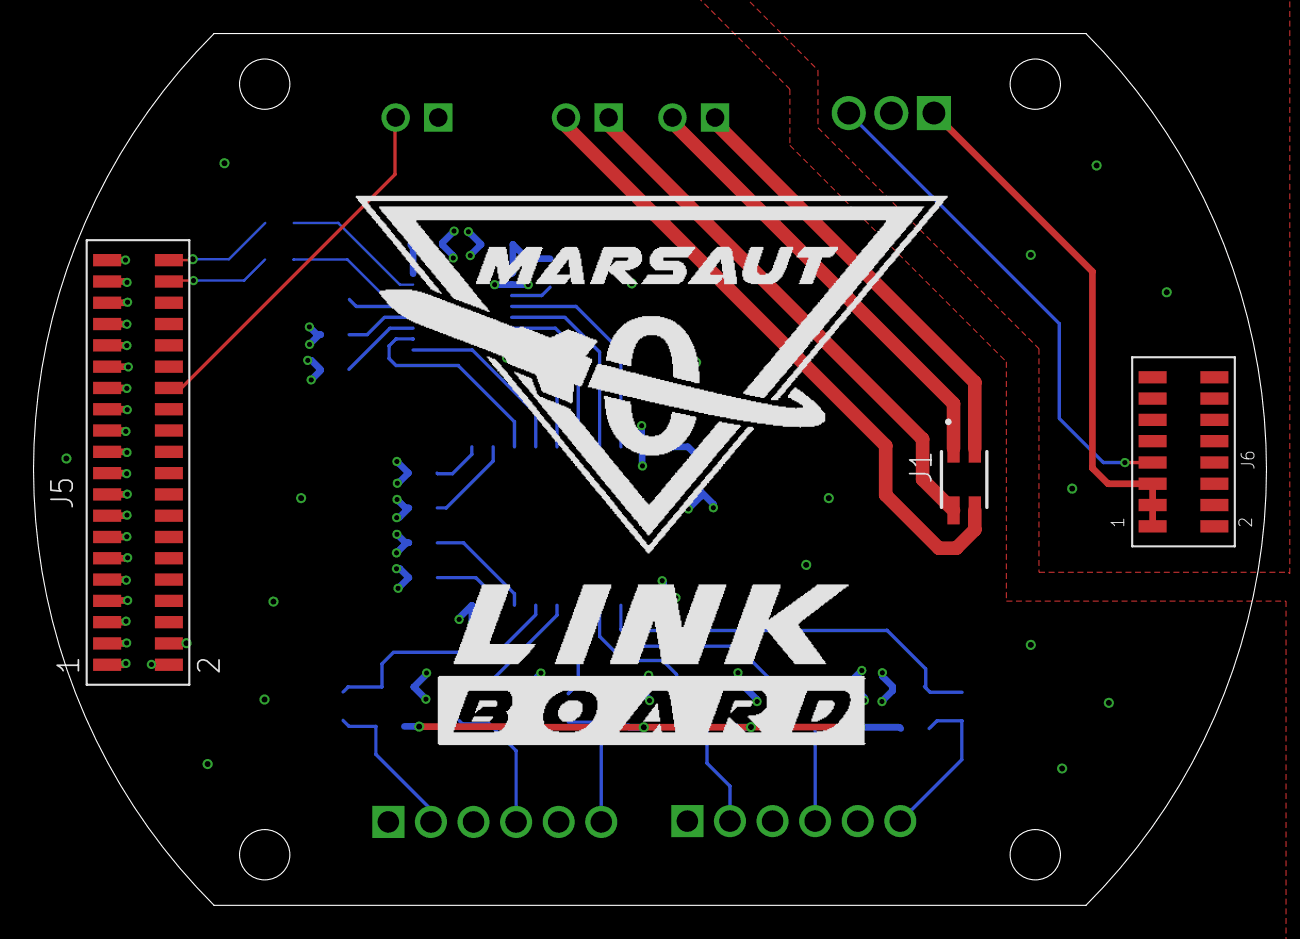
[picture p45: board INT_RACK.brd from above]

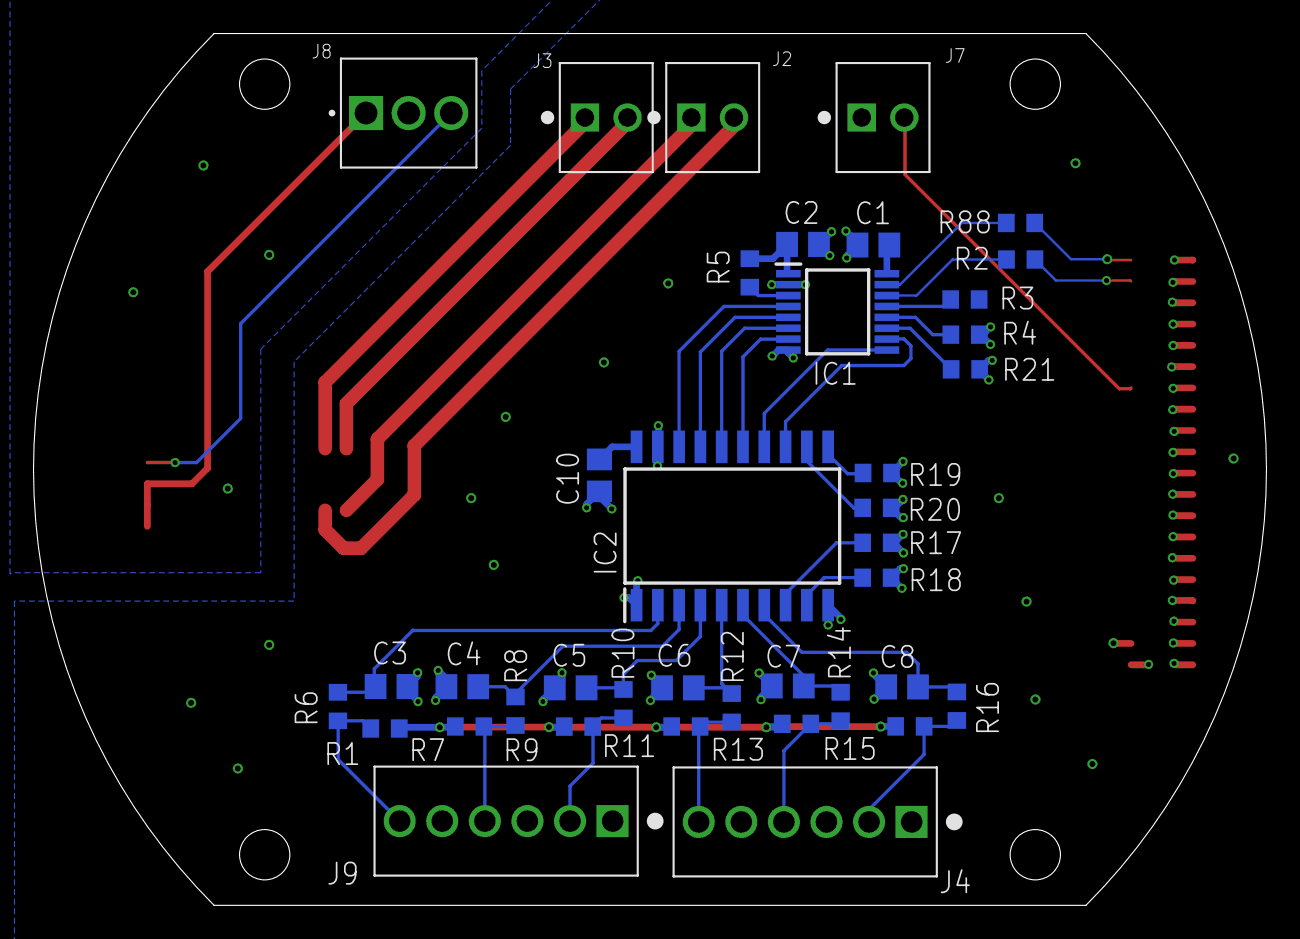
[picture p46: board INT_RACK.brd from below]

Board: 4 copper layers, 73.5 x 52.0 mm, 42 parts (39 on the bottom side), 40 nets.

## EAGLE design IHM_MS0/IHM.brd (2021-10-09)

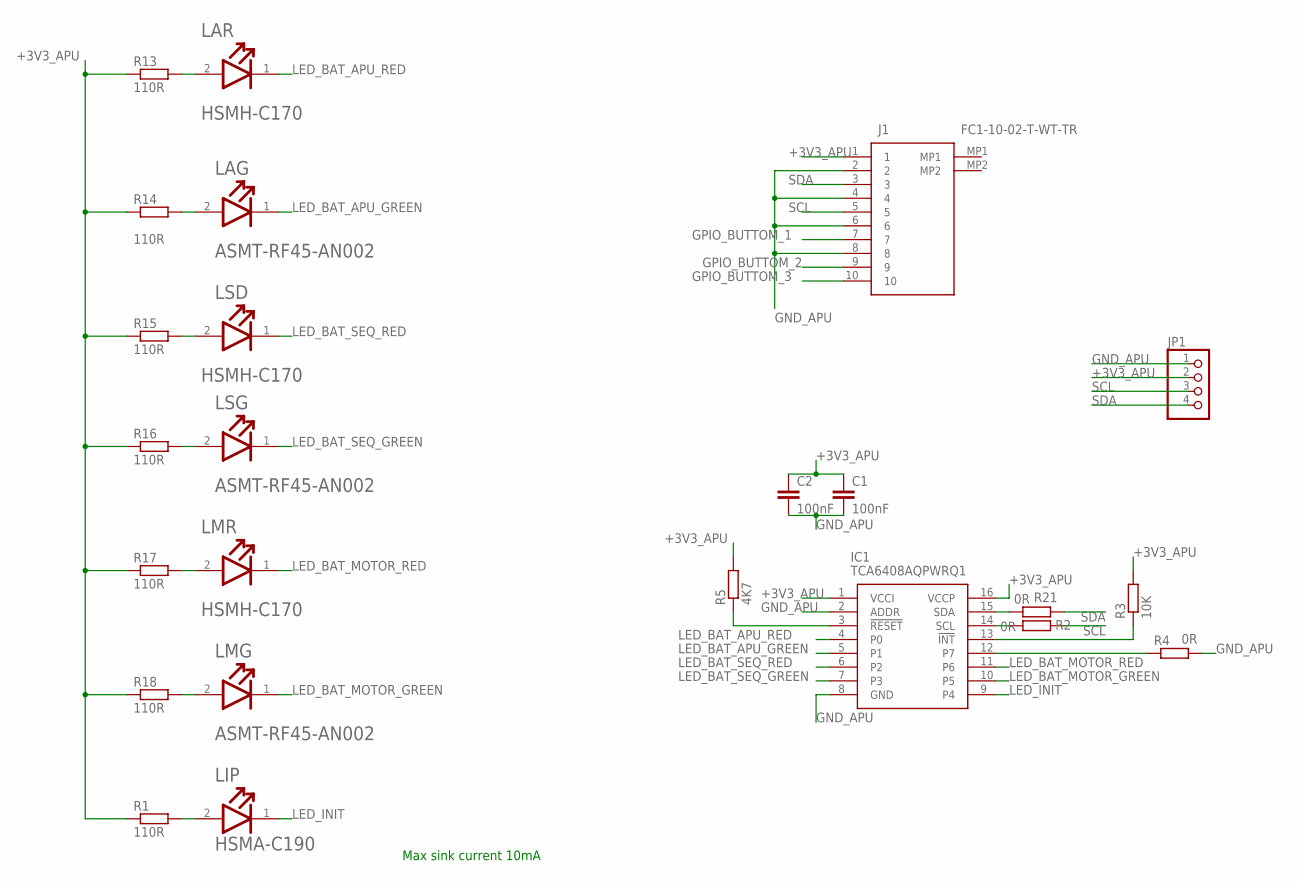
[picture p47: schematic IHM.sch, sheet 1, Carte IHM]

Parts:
C1, C2: 100nF; C0805
IC1: TCA6408AQPWRQ1; SOP65P640X120-16N
J1: FC1-10-02-T-WT-TR; FC11002TWTTR
JP1: PINHD-1X4; 1X04
LAG: BROADCOM_ASMT-RF45-AN002BROADCOM_ASMT-RF45-AN002_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; BROADCOM_ASMT-RF45-AN002_0
LAR: BROADCOM_HSMH-C170BROADCOM_HSMH-C170_0_0; BROADCOM_HSMH-C170_0
LIP: BROADCOM_HSMA-C190BROADCOM_HSMA-C190_0_0; BROADCOM_HSMA-C190_0
LMG: BROADCOM_ASMT-RF45-AN002BROADCOM_ASMT-RF45-AN002_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; BROADCOM_ASMT-RF45-AN002_0
LMR: BROADCOM_HSMH-C170BROADCOM_HSMH-C170_0_0; BROADCOM_HSMH-C170_0
LSD: BROADCOM_HSMH-C170BROADCOM_HSMH-C170_0_0; BROADCOM_HSMH-C170_0
LSG: BROADCOM_ASMT-RF45-AN002BROADCOM_ASMT-RF45-AN002_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; BROADCOM_ASMT-RF45-AN002_0
R1, R13, R14, R15, R16, R17, R18: 110R; R0603
R2, R4, R21: 0R; R0603
R3: 10K; R0603
R5: 4K7; R0603

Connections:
+3V3_APU: C1.1, C2.1, IC1.1 (VCCI), IC1.16 (VCCP), J1.1, JP1.2, R1.1, R3.2, R5.2, R13.1, R14.1, R15.1, R16.1, R17.1, R18.1; also elsewhere on the board
GND_APU: C1.2, C2.2, IC1.2 (ADDR), IC1.8 (GND), J1.2, J1.4, J1.6, J1.8, JP1.1, R4.2; also elsewhere on the board
GPIO_BUTTOM_1: J1.7; also elsewhere on the board
GPIO_BUTTOM_2: J1.9; also elsewhere on the board
GPIO_BUTTOM_3: J1.10; also elsewhere on the board
LED_BAT_APU_GREEN: IC1.5 (P1), LAG.1 (CATHODE)
LED_BAT_APU_RED: IC1.4 (P0), LAR.1 (CATHODE)
LED_BAT_MOTOR_GREEN: IC1.10 (P5), LMG.1 (CATHODE)
LED_BAT_MOTOR_RED: IC1.11 (P6), LMR.1 (CATHODE)
LED_BAT_SEQ_GREEN: IC1.7 (P3), LSG.1 (CATHODE)
LED_BAT_SEQ_RED: IC1.6 (P2), LSD.1 (CATHODE)
LED_INIT: IC1.9 (P4), LIP.1 (CATHODE)
unnamed: LIP.2 (ANODE), R1.2
unnamed: IC1.14 (SCL), R2.2
unnamed: IC1.13 (!INT), R3.1
unnamed: IC1.12 (P7), R4.1
unnamed: IC1.3 (!RESET), R5.1
unnamed: LAR.2 (ANODE), R13.2
unnamed: LAG.2 (ANODE), R14.2
unnamed: LSD.2 (ANODE), R15.2
unnamed: LSG.2 (ANODE), R16.2
unnamed: IC1.15 (SDA), R21.2
unnamed: LMR.2 (ANODE), R17.2
unnamed: LMG.2 (ANODE), R18.2
SCL: J1.5, JP1.3, R2.1
SDA: J1.3, JP1.4, R21.1

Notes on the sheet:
Max sink current 10mA


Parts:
C3, C5, C7: 2u2F; C0805K
C4, C6, C8: 100nF; C0805K
R6, R7, R8, R9, R19, R20: 10K; R0603
R10, R11, R12: 1K; R0603
SW1, SW2, SW3: 147873-1; SW_147873-1
U1, U2, U3: SN74LVC1G17DCKR; SOT65P210X110-5N

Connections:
+3V3_APU: C4.1, C6.1, C8.1, R6.2, R7.2, R8.2, R9.2, R19.2, R20.2, U1.5 (VCC), U2.5 (VCC), U3.5 (VCC); also elsewhere on the board
GND_APU: C3.2, C4.2, C5.2, C6.2, C7.2, C8.2, SW1.1, SW2.1, SW3.1, U1.3 (GND), U2.3 (GND), U3.3 (GND); also elsewhere on the board
GPIO_BUTTOM_1: R20.1, U3.4 (Y); also elsewhere on the board
GPIO_BUTTOM_2: R7.1, U1.4 (Y); also elsewhere on the board
GPIO_BUTTOM_3: R9.1, U2.4 (Y); also elsewhere on the board
unnamed: C3.1, R10.2, U1.2 (A)
unnamed: R6.1, R10.1, SW2.2
unnamed: C5.1, R12.2, U2.2 (A)
unnamed: R8.1, R12.1, SW3.2
unnamed: C7.1, R11.2, U3.2 (A)
unnamed: R11.1, R19.1, SW1.2

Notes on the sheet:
Schmidt Trigger
T=RC = 22ms



Board: 4 copper layers, 43.0 x 42.2 mm, 45 parts (20 on the bottom side), 32 nets.

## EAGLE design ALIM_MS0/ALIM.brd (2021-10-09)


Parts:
BT1: BH600; BAT_BH600
C1, C3, C5: 100nF; C0805
C2, C6: 10uF; C0805
C4: 22uF; C0805
J1: 282834-2; CONN_282834-2
J4: FTSH-108-05-F-DV-A; FTSH-108-XX-YYY-DV-A
L1: LQH5BPB2R2NT0L; IND_LQH5BPB2R2NT0L
Q1: VISHAY_SI7463DP-T1-E3VISHAY_SI7463DP-T1-E3_0_0; VISHAY_SI7463DP-T1-E3_0
R1: 33.2K; R0603
R2, R6, R10: 10K; R0603
R3: 100R; R0603
R7: 3K; R0603
R8: 12K; R0603
R9: 13k; R0603
R11: 0R; R0603
TLV1: TLV9022
U10: TPS565201DDCR; SOT95P280X110-6N

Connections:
1WIRE: J4.7
3V: BT1.+, J4.15
+3V3_APU: C4.1, C5.1, J4.1, J4.3, J4.5, L1.2, R1.2, R8.1, R10.2, TLV1.V+
BAT_APU_9V: C1.1, C2.1, Q1.1 (1_S), Q1.2 (2_S), Q1.3 (3_S), R9.1, U10.3 (VIN), U10.5 (EN)
CON_BAT_APU_9V: J1.1, Q1.5-6-7-8 (D)
GND_APU: BT1.-, C1.2, C2.2, C4.2, C5.2, C6.2, J1.2, J4.2, J4.4, J4.6, J4.8, J4.10, J4.12, J4.14, J4.16, R2.1, R3.1, R6.1, R7.1, TLV1.IN2+, TLV1.IN2-, TLV1.V-, U10.1 (GND)
MONITORING_ALIM_APU: J4.13, R11.2
unnamed: Q1.4 (G), R3.2
unnamed: C3.1, U10.6 (VBST)
unnamed: C3.2, L1.1, U10.2 (SW)
unnamed: R1.1, R2.2, U10.4 (VFB)
unnamed: R6.2, R8.2, TLV1.IN1+
unnamed: C6.1, R7.2, R9.2, TLV1.IN1-
unnamed: R10.1, R11.1, TLV1.OUT1
RX_APU: J4.11
TX_APU: J4.9

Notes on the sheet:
C1 & C2 min support 25V Current max 4 A à 25° pour L1 Iout = 2 A max F = 500kHz
Model open drain output
T=RC=100ms
Comparateur
Convertiseur DC/DC Buck
Seuil de niveau (calcul pont diviseur) à 8 V
Partie APU


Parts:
C7, C10, C12: 100nF; C0805
C8, C9, C11: 10uF; C0805
C13: 22uF; C0805
J2, J5: 282834-2; CONN_282834-2
J3: FTSH-120-05-F-DV; FTSH-120-XX-YYY-DV
L2: LQH5BPB2R2NT0L; IND_LQH5BPB2R2NT0L
Q2, Q3: VISHAY_SI7463DP-T1-E3VISHAY_SI7463DP-T1-E3_0_0; VISHAY_SI7463DP-T1-E3_0
R4, R5: 100R; R0603
R12, R17: 12K; R0603
R13: 13K; R0603
R14, R16: 3K; R0603
R15, R19, R20, R21, R25: 10K; R0603
R18: 13k; R0603
R22, R23: 0R; R0603
R24: 33.2K; R0603
TLV2: TLV9022
U11: TPS565201DDCR; SOT95P280X110-6N

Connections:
+3V3: C7.1, C13.1, J3.4, L2.2, R12.2, R17.1, R20.2, R21.2, R24.2, TLV2.V+
BAT_MOTOR_9V: J3.6, Q3.1 (1_S), Q3.2 (2_S), Q3.3 (3_S), R13.1
BAT_SEQ_9V: C10.1, C11.1, Q2.1 (1_S), Q2.2 (2_S), Q2.3 (3_S), R18.1, U11.3 (VIN), U11.5 (EN)
CON_BAT_MOTOR_9V: J5.2, Q3.5-6-7-8 (D)
CON_BAT_SEQ_9V: J2.2, Q2.5-6-7-8 (D)
CURRENT_SENS_M1: J3.8
CURRENT_SENS_M2: J3.10
EN/DIA_M1: J3.18
EN/DIA_M2: J3.14
EN/DIB_M1: J3.16
EN/DIB_M2: J3.12
GND: C7.2, C8.2, C9.2, C10.2, C11.2, C13.2, J2.1, J3.1, J3.2, J3.3, J3.5, J3.7, J3.9, J3.11, J3.13, J3.15, J3.17, J3.19, J3.21, J3.23, J3.25, J3.27, J3.29, J3.31, J3.33, J3.35, J3.37, J3.39, J5.1, R4.1, R5.1, R14.1, R15.1, R16.1, R19.1, R25.1, TLV2.V-, U11.1 (GND)
INA_M1: J3.26
INA_M2: J3.22
INB_M1: J3.24
INB_M2: J3.20
JACK: J3.28
MONITORING_ALIM_MOTOR: J3.34, R22.2
MONITORING_ALIM_SEQ: J3.36, R23.2
unnamed: Q2.4 (G), R4.2
unnamed: Q3.4 (G), R5.2
unnamed: R12.1, R19.2, TLV2.IN2+
unnamed: C8.1, R13.2, R14.2, TLV2.IN2-
unnamed: R15.2, R17.2, TLV2.IN1+
unnamed: C9.1, R16.2, R18.2, TLV2.IN1-
unnamed: R20.1, R22.1, TLV2.OUT2
unnamed: R21.1, R23.1, TLV2.OUT1
unnamed: C12.1, U11.6 (VBST)
unnamed: C12.2, L2.1, U11.2 (SW)
unnamed: R24.1, R25.2, U11.4 (VFB)
PWM_M1: J3.30
PWM_M2: J3.32
SCL_SEQ: J3.38
SDA_SEQ: J3.40

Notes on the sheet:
C3 et C4 non monté
C1 & C2 min support 25V Current max 4 A à 25° pour L1 Iout = 2 A max F = 500kHz
Model open drain output
T=RC=100ms
Connecteur 20 broches SEQ
Comparateur : donner l'info de décharge de 50%
Seuil de niveau (calcul pont diviseur) à 8 V
Partie SEQ



Board: 4 copper layers, 73.5 x 52.0 mm, 53 parts (2 on the bottom side), 32 nets.

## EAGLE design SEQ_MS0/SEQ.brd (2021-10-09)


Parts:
C1, C2: 4u7F; C0805K
C3: 1uF; C0805K
C4: 0.1uF; C0805K
C6, C7: 100nF; C0805
D1: BROADCOM_ASMT-RF45-AN002BROADCOM_ASMT-RF45-AN002_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; BROADCOM_ASMT-RF45-AN002_0
D2: NRVTS260ESFT1G; SODFL3616X98N
D3: BROADCOM_HSMA-C190BROADCOM_HSMA-C190_0_0; BROADCOM_HSMA-C190_0
FB2: TDK_MMZ1608S601ATA00TDK_MMZ1608S601ATA00_0_0; TDK_MMZ1608S601ATA00_0
J6: SAMTEC-TSM-103-01-X-DHJ; SAMTEC-TSM-103-01-X-DH
LS1: CSS-0575A-SMT; CUI_CSS-0575A-SMT
Q2: NTR4501NT1G; SOT95P237X111-3N
R1, R18, R19, R20, R21: 0R; R0603
R2, R27: 10K; R0603
R5, R6: 110R; R0603
R7: 330R; R0603
R8, R9: 4K7; R0603
R10: 100k; R0603
R15, R16, R17: 100K; R0603
SW2: 147873-1; SW_147873-1
U2: STM32F303K8T6; QFP80P900X900X160-32N
U4: ADUM226N1BRIZ; RI_8_1_ADI

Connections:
+3V3: C1.1, C2.1, C6.1, D2.1 (K), FB2.2, J6.1, LS1.1, R5.1, R8.2, R9.2, U2.1 (VDD_1), U2.17 (VDD_2), U4.1 (VDD1); also elsewhere on the board
+3V3_APU: C7.1, U4.8 (VDD2); also elsewhere on the board
CURRENT_SENS_M1: U2.15 (PB1); also elsewhere on the board
CURRENT_SENS_M2: U2.14 (PB0); also elsewhere on the board
EN/DIA_M1: U2.10 (PA4); also elsewhere on the board
EN/DIA_M2: U2.12 (PA6); also elsewhere on the board
EN/DIB_M1: U2.11 (PA5); also elsewhere on the board
EN/DIB_M2: U2.13 (PA7); also elsewhere on the board
GATE: Q2.1 (G), R7.2, R27.2
GND: C1.2, C2.2, C3.2, C4.2, C6.2, D1.1 (CATHODE), D3.1 (CATHODE), J6.5, Q2.2 (S), R2.1, R10.1, R15.1, R27.1, SW2.1, U2.16 (VSS_2), U2.32 (VSS_1), U4.4 (GND1); also elsewhere on the board
GND_APU: C7.2, R16.1, R17.1, U4.5 (GND2); also elsewhere on the board
INA_M1: U2.6 (PA0); also elsewhere on the board
INA_M2: U2.8 (PA2); also elsewhere on the board
INB_M1: U2.7 (PA1); also elsewhere on the board
INB_M2: U2.9 (PA3); also elsewhere on the board
JACK: U2.18 (PA8); also elsewhere on the board
MONITORING_ALIM_MOTOR: U2.27 (PB4); also elsewhere on the board
MONITORING_ALIM_SEQ: U2.28 (PB5); also elsewhere on the board
unnamed: C3.1, FB2.1, U2.5 (VDDA/VREF+)
unnamed: R2.2, U2.31 (BOOT0)
unnamed: R1.1, SW2.2
unnamed: D1.2 (ANODE), R5.2
unnamed: D3.2 (ANODE), R6.2
unnamed: R10.2, R19.2, U4.3 (VIB)
unnamed: R15.2, R18.2, U4.2 (VOA)
unnamed: R16.2, R20.1, U4.7 (VIA)
unnamed: R17.2, R21.1, U4.6 (VOB)
unnamed: D2.2 (A), LS1.2 (N), Q2.3 (D)
NRST: C4.1, J6.3, R1.2, U2.4 (NRST)
PWM_BUZZER: R7.1, U2.2 (PF0/OSC_IN)
PWM_M1: U2.21 (PA11); also elsewhere on the board
PWM_M2: U2.22 (PA12); also elsewhere on the board
RST_DS: U2.3 (PF1/OSC_OUT); also elsewhere on the board
RX_APU: R21.2; also elsewhere on the board
RX_SEQ: R18.1, U2.20 (PA10); also elsewhere on the board
SCL: R9.1, U2.29 (PB6); also elsewhere on the board
SDA: R8.1, U2.30 (PB7); also elsewhere on the board
SWCLK: J6.4, U2.24 (PA14)
SWDIO: J6.2, R6.1, U2.23 (PA13)
TX_APU: R20.2; also elsewhere on the board
TX_SEQ: R19.1, U2.19 (PA9); also elsewhere on the board

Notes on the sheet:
T=RC = 22ms
Attention inversion des TX & RX sur l'ADUM !


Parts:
C8, C9, C10, C12: 100nF; C0805
C11: 2.2nF; C0805
D4, D5, D6, D7: BROADCOM_HSMH-C170BROADCOM_HSMH-C170_0_0; BROADCOM_HSMH-C170_0
R11, R12, R13, R14: 110R; R0603
R22, R23, R24, R25, R26: 0R; R0603
U5: DS3231S; SOIC127P1032X265-16N
U6: MPU-6050; QFN50P400X400X95-24N

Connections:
+3V3: C8.1, C9.2, C10.2, U5.2 (VCC), U6.8 (VLOGIC), U6.9 (AD0), U6.13 (VDD); also elsewhere on the board
GND: C8.2, C9.1, C10.1, C11.1, C12.1, D4.1 (CATHODE), D5.1 (CATHODE), U5.5 (N.C.), U5.6 (N.C.), U5.7 (N.C.), U5.8 (N.C.), U5.9 (N.C.), U5.10 (N.C.), U5.11 (N.C.), U5.12 (N.C.), U5.13 (GND), U6.1 (CLKIN), U6.11 (FSYNC), U6.18 (GND); also elsewhere on the board
GND_APU: D6.1 (CATHODE), D7.1 (CATHODE); also elsewhere on the board
unnamed: D4.2 (ANODE), R14.2
unnamed: D5.2 (ANODE), R11.2
unnamed: D7.2 (ANODE), R12.2
unnamed: D6.2 (ANODE), R13.2
unnamed: R22.1, U5.15 (SDA)
unnamed: R23.1, U5.16 (SCL)
unnamed: R24.1, U5.4 (!RST)
unnamed: R26.2, U6.24 (SDA)
unnamed: R25.2, U6.23 (SCL)
unnamed: C12.2, U6.10 (REGOUT)
unnamed: C11.2, U6.20 (CPOUT)
RST_DS: R24.2; also elsewhere on the board
RX_APU: R13.1; also elsewhere on the board
RX_SEQ: R11.1; also elsewhere on the board
SCL: R23.2, R25.1; also elsewhere on the board
SDA: R22.2, R26.1; also elsewhere on the board
TX_APU: R12.1; also elsewhere on the board
TX_SEQ: R14.1; also elsewhere on the board
VBAT: U5.14 (VBAT)


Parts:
J1: FTSH-108-05-F-DV-A; FTSH-108-XX-YYY-DV-A
J2: FLE-108-01-XX-DV
J3: FTSH-120-05-F-DV; FTSH-120-XX-YYY-DV
J5: FLE-120-01-XX-DV

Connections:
1WIRE: J1.7, J2.7
3V: J1.15, J2.15
+3V3: J3.4, J5.4; also elsewhere on the board
+3V3_APU: J1.1, J1.3, J1.5, J2.1, J2.3, J2.5; also elsewhere on the board
BAT_MOTOR_9V: J3.6, J5.6
CURRENT_SENS_M1: J3.8, J5.8; also elsewhere on the board
CURRENT_SENS_M2: J3.10, J5.10; also elsewhere on the board
EN/DIA_M1: J3.18, J5.18; also elsewhere on the board
EN/DIA_M2: J3.14, J5.14; also elsewhere on the board
EN/DIB_M1: J3.16, J5.16; also elsewhere on the board
EN/DIB_M2: J3.12, J5.12; also elsewhere on the board
GND: J3.1, J3.2, J3.3, J3.5, J3.7, J3.9, J3.11, J3.13, J3.15, J3.17, J3.19, J3.21, J3.23, J3.25, J3.27, J3.29, J3.31, J3.33, J3.35, J3.37, J3.39, J5.1, J5.2, J5.3, J5.5, J5.7, J5.9, J5.11, J5.13, J5.15, J5.17, J5.19, J5.21, J5.23, J5.25, J5.27, J5.29, J5.31, J5.33, J5.35, J5.37, J5.39; also elsewhere on the board
GND_APU: J1.2, J1.4, J1.6, J1.8, J1.10, J1.12, J1.14, J1.16, J2.2, J2.4, J2.6, J2.8, J2.10, J2.12, J2.14, J2.16; also elsewhere on the board
INA_M1: J3.26, J5.26; also elsewhere on the board
INA_M2: J3.22, J5.22; also elsewhere on the board
INB_M1: J3.24, J5.24; also elsewhere on the board
INB_M2: J3.20, J5.20; also elsewhere on the board
JACK: J3.28, J5.28; also elsewhere on the board
MONITORING_ALIM_APU: J1.13, J2.13
MONITORING_ALIM_MOTOR: J3.34, J5.34; also elsewhere on the board
MONITORING_ALIM_SEQ: J3.36, J5.36; also elsewhere on the board
PWM_M1: J3.30, J5.30; also elsewhere on the board
PWM_M2: J3.32, J5.32; also elsewhere on the board
RX_APU: J1.11, J2.11; also elsewhere on the board
SCL: J3.38, J5.38; also elsewhere on the board
SDA: J3.40, J5.40; also elsewhere on the board
TX_APU: J1.9, J2.9; also elsewhere on the board



Board: 4 copper layers, 73.5 x 52.0 mm, 56 parts (3 on the bottom side), 56 nets.

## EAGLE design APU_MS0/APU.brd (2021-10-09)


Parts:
BMP: BMP280; XDCR_BMP280
C1, C2, C4, C5, C7, C9, C10, C13: 100nF; C0805
C12: 2.2nF; C0805
DS: DS3231S; SOIC127P1032X265-16N
J1: MEM2067-02-180-00-A_REVB; GCT_MEM2067-02-180-00-A_REVB
MPU: MPU-6050; QFN50P400X400X95-24N
R1, R2, R3, R4, R7, R8, R9, R11, R12, R13: 0R; R0603

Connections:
3V: C9.1, DS.14 (VBAT); also elsewhere on the board
+3V3_APU: BMP.2 (CSB), BMP.6 (VDDIO), BMP.8 (VDD), C1.2, C2.2, C4.1, C5.1, C7.1, C10.1, DS.2 (VCC), J1.4 (VDD), MPU.8 (VLOGIC), MPU.9 (AD0), MPU.13 (VDD); also elsewhere on the board
GND_APU: BMP.1 (GND), BMP.5 (SDO), BMP.7 (GND), C1.1, C2.1, C4.2, C5.2, C7.2, C9.2, C10.2, C12.1, C13.1, DS.5 (N.C.), DS.6 (N.C.), DS.7 (N.C.), DS.8 (N.C.), DS.9 (N.C.), DS.10 (N.C.), DS.11 (N.C.), DS.12 (N.C.), DS.13 (GND), J1.2 (CD/DAT3), J1.6 (VSS), J1.9 (SHIELD), J1.10 (SHIELD), J1.11 (SHIELD), J1.12 (SHIELD), MPU.1 (CLKIN), MPU.11 (FSYNC), MPU.18 (GND); also elsewhere on the board
MISO: R11.2; also elsewhere on the board
MOSI: R12.2; also elsewhere on the board
N301: BMP.3 (SDI), R3.2
N303: BMP.4 (SCK), R4.2
unnamed: MPU.24 (SDA), R2.2
unnamed: MPU.23 (SCL), R1.2
unnamed: C13.2, MPU.10 (REGOUT)
unnamed: DS.15 (SDA), R7.1
unnamed: DS.16 (SCL), R8.1
unnamed: DS.4 (!RST), R9.1
unnamed: J1.7 (DAT0), R11.1
unnamed: J1.5 (CLK), R13.1
unnamed: J1.3 (CMD), R12.1
unnamed: C12.2, MPU.20 (CPOUT)
RST_DS: R9.2; also elsewhere on the board
SCL: R1.1, R4.1, R8.2; also elsewhere on the board
SCLK: R13.2; also elsewhere on the board
SDA: R2.1, R3.1, R7.2; also elsewhere on the board

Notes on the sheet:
5pF input Capacitor
10pF input Capacitor


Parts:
J3: FTSH-120-05-F-DV; FTSH-120-XX-YYY-DV
J4: FTSH-108-05-F-DV-A; FTSH-108-XX-YYY-DV-A
J5: FLE-120-01-XX-DV
J6: FLE-108-01-XX-DV
J7: FC1-05-02-T-WT-TR; FC10502TWTTR
J8: FC1-10-02-T-WT-TR; FC11002TWTTR

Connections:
1WIRE: J4.7, J6.7; also elsewhere on the board
3V: J4.15, J6.15; also elsewhere on the board
+3V3: J3.4, J5.4
+3V3_APU: J4.1, J4.3, J4.5, J6.1, J6.3, J6.5, J8.1; also elsewhere on the board
BAT_MOTOR_9V: J3.6, J5.6
CURRENT_SENS_M1: J3.8, J5.8
CURRENT_SENS_M2: J3.10, J5.10
EN/DIA_M1: J3.18, J5.18
EN/DIA_M2: J3.14, J5.14
EN/DIB_M1: J3.16, J5.16
EN/DIB_M2: J3.12, J5.12
GND: J3.1, J3.2, J3.3, J3.5, J3.7, J3.9, J3.11, J3.13, J3.15, J3.17, J3.19, J3.21, J3.23, J3.25, J3.27, J3.29, J3.31, J3.33, J3.35, J3.37, J3.39, J5.1, J5.2, J5.3, J5.5, J5.7, J5.9, J5.11, J5.13, J5.15, J5.17, J5.19, J5.21, J5.23, J5.25, J5.27, J5.29, J5.31, J5.33, J5.35, J5.37, J5.39
GND_APU: J4.2, J4.4, J4.6, J4.8, J4.10, J4.12, J4.14, J4.16, J6.2, J6.4, J6.6, J6.8, J6.10, J6.12, J6.14, J6.16, J7.2, J7.4, J7.5, J8.2, J8.4, J8.6, J8.8; also elsewhere on the board
GPIO_BUTTOM_1: J8.7; also elsewhere on the board
GPIO_BUTTOM_2: J8.9; also elsewhere on the board
GPIO_BUTTOM_3: J8.10; also elsewhere on the board
INA_M1: J3.26, J5.26
INA_M2: J3.22, J5.22
INB_M1: J3.24, J5.24
INB_M2: J3.20, J5.20
JACK: J3.28, J5.28
MONITORING_ALIM_APU: J4.13, J6.13; also elsewhere on the board
MONITORING_ALIM_MOTOR: J3.34, J5.34
MONITORING_ALIM_SEQ: J3.36, J5.36
PWM_M1: J3.30, J5.30
PWM_M2: J3.32, J5.32
RX_APU: J4.11, J6.11; also elsewhere on the board
RX_LTS: J7.1; also elsewhere on the board
SCL: J8.5; also elsewhere on the board
SCL_SEQ: J3.38, J5.38
SDA: J8.3; also elsewhere on the board
SDA_SEQ: J3.40, J5.40
TX_APU: J4.9, J6.9; also elsewhere on the board
TX_LTS: J7.3; also elsewhere on the board


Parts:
C3, C6: 4u7F; C0805K
C8: 1uF; C0805K
C14: 0.1uF; C0805K
D1: BROADCOM_ASMT-RF45-AN002BROADCOM_ASMT-RF45-AN002_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; BROADCOM_ASMT-RF45-AN002_0
D2: BROADCOM_HSMA-C190BROADCOM_HSMA-C190_0_0; BROADCOM_HSMA-C190_0
D3, D4: BROADCOM_HSMH-C170BROADCOM_HSMH-C170_0_0; BROADCOM_HSMH-C170_0
FB1: TDK_MMZ1608S601ATA00TDK_MMZ1608S601ATA00_0_0; TDK_MMZ1608S601ATA00_0
J2: SAMTEC-TSM-103-01-X-DHJ; SAMTEC-TSM-103-01-X-DH
R5, R6, R21: 4K7; R0603
R10: 10K; R0603
R14, R15, R19, R20: 110R; R0603
R16, R22, R23: 0R; R0603
STM32: STM32F303K8T6; QFP80P900X900X160-32N
SW1: 147873-1; SW_147873-1

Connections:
1WIRE: R21.1, STM32.2 (PF0/OSC_IN); also elsewhere on the board
+3V3_APU: C3.1, C6.1, FB1.2, J2.1, R5.2, R6.2, R15.1, R21.2, STM32.1 (VDD_1), STM32.17 (VDD_2); also elsewhere on the board
GND_APU: C3.2, C6.2, C8.2, C14.2, D1.1 (CATHODE), D2.1 (CATHODE), D3.1 (CATHODE), D4.1 (CATHODE), J2.5, R10.1, STM32.16 (VSS_2), STM32.32 (VSS_1), SW1.1; also elsewhere on the board
GPIO_BUTTOM_1: STM32.10 (PA4); also elsewhere on the board
GPIO_BUTTOM_2: STM32.9 (PA3); also elsewhere on the board
GPIO_BUTTOM_3: STM32.8 (PA2); also elsewhere on the board
MISO: STM32.12 (PA6); also elsewhere on the board
MONITORING_ALIM_APU: STM32.28 (PB5); also elsewhere on the board
MOSI: STM32.13 (PA7); also elsewhere on the board
unnamed: C8.1, FB1.1, STM32.5 (VDDA/VREF+)
unnamed: R10.2, STM32.31 (BOOT0)
unnamed: D1.2 (ANODE), R15.2
unnamed: D3.2 (ANODE), R19.2
unnamed: D4.2 (ANODE), R20.2
unnamed: R22.2, STM32.19 (PA9)
unnamed: R23.2, STM32.20 (PA10)
unnamed: D2.2 (ANODE), R14.2
unnamed: R16.1, SW1.2
NRST: C14.1, J2.3, R16.2, STM32.4 (NRST)
RST_DS: STM32.3 (PF1/OSC_OUT); also elsewhere on the board
RX_APU: STM32.27 (PB4); also elsewhere on the board
RX_LTS: R20.1, R23.1; also elsewhere on the board
SCL: R6.1, STM32.29 (PB6); also elsewhere on the board
SCLK: STM32.11 (PA5); also elsewhere on the board
SDA: R5.1, STM32.30 (PB7); also elsewhere on the board
SWCLK: J2.4, STM32.24 (PA14)
SWDIO: J2.2, R14.1, STM32.23 (PA13)
TX_APU: STM32.26 (PB3); also elsewhere on the board
TX_LTS: R19.1, R22.1; also elsewhere on the board

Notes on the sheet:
7pF input Capacitor PCF8574A
TX1 & RX1 Non Inversé -> LTS TX2 & RX2 Non INVERS2 -> Séquenceur
T=RC = 22ms

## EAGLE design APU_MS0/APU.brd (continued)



Board: 4 copper layers, 73.5 x 52.0 mm, 52 parts (10 on the bottom side), 62 nets.

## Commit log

2021-10-09 Apu board add
    [APU.brd, APU.sch, APU_BOM.xlsx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]
2021-10-09 SEQ board add
    [SEQ.brd, SEQ.sch, SEQ_BOM.xlsx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]
2021-10-09 ALIM board add
    [ALIM.brd, ALIM.csv, ALIM.sch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]
2021-10-09 IHM board add
    [IHM.brd, IHM.csv, IHM.sch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]
2021-10-09 LINK board add
    [INT_RACK.brd, INT_RACK.sch, LINK_BOM.xlsx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]
2021-10-09 MOTOR board add
    [MOTOR_BOM.xlsx, PnP_motor_back.csv, PnP_motor_front.csv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]
2021-10-09 INT_LTS board add
    [INT_LTS.brd, INT_LTS.csv, INT_LTS.sch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]
2021-10-09 add component lib eagle
    [06695f22abd46c4b359e0e4e7049cb9a821bc6c2.step, 1-215297-5--3DModel-STEP-1 (1).STEP, 1048P--3DModel-STEP-56544.STEP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]
2021-10-15 add all schematic

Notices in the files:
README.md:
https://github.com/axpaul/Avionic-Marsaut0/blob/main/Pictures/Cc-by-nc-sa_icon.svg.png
